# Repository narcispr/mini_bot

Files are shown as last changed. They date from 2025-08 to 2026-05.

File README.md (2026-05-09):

# MiniBot

MiniBot is a easy to mount and moderately cheap robot platform for learning and prototyping in robotics. It is designed to be simple to assemble and use, making it ideal for beginners and hobbyists.

## Construction

To construct the MiniBot, you will need to print the 3D parts available in the [parts](parts) directory. The parts are designed to be printed using a standard FDM 3D printer with PLA.

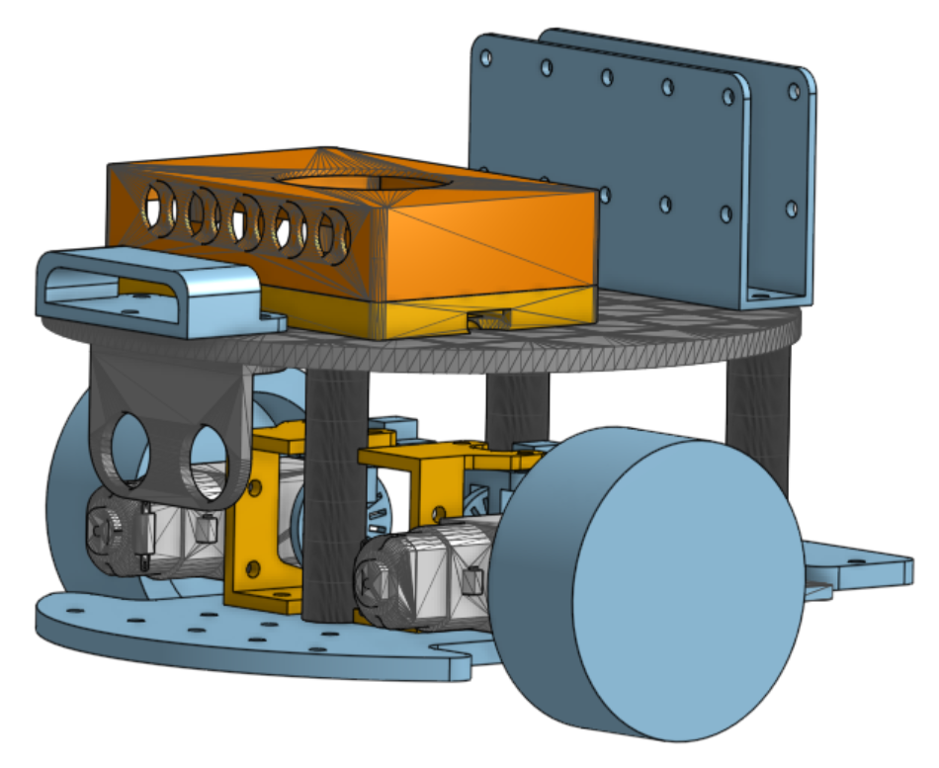
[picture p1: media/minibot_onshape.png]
MiniBot


# Bill of Materials (BOM)

| Item | Qty | Approx. price (EUR) | Notes |
|---|---:|---:|---|
| 3D-printed parts | — | — | See `parts/` directory for STLs and print settings. |
| Arduino Uno (compatible) | 1 | ~€6-20€ | Fully Uno-compatible, USB cable included. |
| Raspberry Pi 4/5 Model B (4GB/8GB) | 1 | ~€60-120€ | Good value & widely available. |
| Adafruit Motor Shield v1 compatible | 1 | ~€4 | v1 compatible shields can be found at Aliexpress and similar. |
| TT motors with wheels (pair) | 1 set | ~€8 | Consider better motors |
| TT wheel encoders (pair) | 1 set | ~€6 | Discs + accessories; pair with IR sensors as needed. |
| Caster wheel | 1 | ~€3 | Any 10–20 mm low-profile caster works. |
| Ultrasonic sensor (HC-SR04) | 1 | ~€2–€6 | Multipacks are cheaper per unit. |
| Webcam (Logitech C270) | 1 | ~€25–€30 | 720p is enough for vision demos. |
| Battery pack for motors | 1 | ~€4–€7 | Option A (4×AA, 6 V) or Option B (6×AA, 9 V). Use quality NiMH cells. |
| Power bank for Raspberry Pi (5 V USB) | 1 | ~€22–€30 | ≥10 000 mAh works; 20 000 mAh gives longer runtime. |
| M3 screws, nuts, spacers | Varies | ~€5–€10 | from 5m to 30m length |

---

**Rough total** 
~€150-210€, excluding 3D prints and AA cells but including Raspberry Pi and many components that you may already have.

### Assembly

There are no detailed assembly instructions yet, but the design is intended to be intuitive. Look at the following images for guidance:

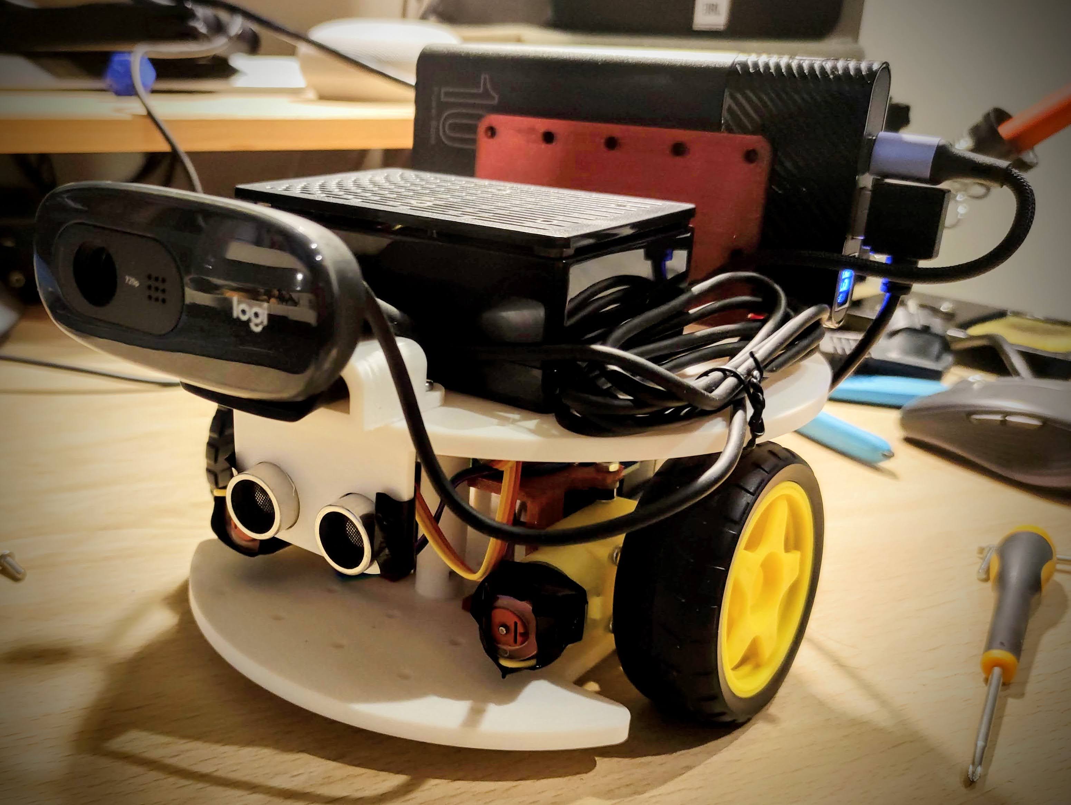
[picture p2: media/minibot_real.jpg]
MiniBot Assembly


## Software
The software for the MiniBot robot is divided in two parts: the Arduino code and the Raspberry Pi code. The communications between the two parts is done using serial communication (USB).

### Arduino Code
The Arduino code is responsible for controlling the motors and reading the sensors. It can be found in the [arduino](arduino) directory. To upload the code to your Arduino board, open the `firmware.ino` file in the Arduino IDE and upload it to your board.

### Raspberry Pi Code
The Raspberry Pi code is responsible for higher-level functions such as image processing and navigation. A ROS2 package is available in this repository. To use it, you will need to have ROS2 installed on your Raspberry Pi. ROS2 Jazzy has been the one used for testing, but other versions may work as well.

There is another repository with the MiniBot description available at [https://github.com/narcispr/mini_bot_description](https://github.com/narcispr/mini_bot_description).

### ROS dependencies

Install the package dependencies from the workspace root:

```bash
cd ~/ros2_ws
rosdep install --from-paths src --ignore-src -r -y
```

For OctoMap support on ROS 2 Jazzy, install:

```bash
sudo apt update
sudo apt install ros-jazzy-octomap-server
```

Optional RViz plugins for visualizing OctoMap messages:

```bash
sudo apt install ros-jazzy-octomap-rviz-plugins
```

If the USB camera node is enabled in `launch/mini_bot.launch.py`, also install:

```bash
sudo apt install ros-jazzy-usb-cam
```

Build and source the workspace after installing dependencies:

```bash
cd ~/ros2_ws
colcon build --packages-select mini_bot
source install/setup.bash
```

### Running with OctoMap Server

`launch/run_robot.launch.py` starts the MiniBot nodes, `robot_state_publisher`, and `octomap_server`. The OctoMap server consumes the MiniBot ultrasonic point cloud:

- input topic: `/range_pointcloud`
- OctoMap subscription: `cloud_in`, remapped to `/range_pointcloud`
- sensor frame: `range_link`
- fixed map frame: `odom`
- resolution: `0.05` m
- maximum sensor range: `3.0` m

Run it with:

```bash
ros2 launch mini_bot run_robot.launch.py
```

The required TF chain is:

```text
odom -> base_link -> range_link
```

`navigation_node` publishes `odom -> base_link`, and `robot_state_publisher` publishes `base_link -> range_link` from the URDF in `mini_bot_description`.

Useful checks:

```bash
ros2 topic info /range_pointcloud
ros2 run tf2_ros tf2_echo odom range_link
ros2 topic echo /projected_map --once
```

The most useful OctoMap outputs are:

- `/projected_map`: 2D occupancy grid projection.
- `/octomap_binary`: compact 3D OctoMap.
- `/octomap_full`: full 3D OctoMap.

### Magnetometer calibration

The robot can use the magnetometer heading as an external orientation source by setting:

```yaml
navigation_node:
  ros__parameters:
    use_external_theta: True
```

There are two simple calibration layers:

1. `mini_bot_node` corrects the raw X/Y magnetometer readings before publishing `/compass_angle`.
2. `navigation_node` maps measured headings to robot-relative headings with `external_theta_calibration_lut`.

#### Automatic raw X/Y calibration

The `mini_bot_node` provides a service that rotates the robot, records magnetometer min/max values, updates the raw X/Y calibration parameters, and writes them back to `config/mini_bot.yaml`.

For calibration, first run with the compass disabled in `config/mini_bot.yaml`:

```yaml
navigation_node:
  ros__parameters:
    use_external_theta: False
```

Start the robot on a flat surface with enough free space to rotate:

```bash
ros2 launch mini_bot run_robot.launch.py
```

Call the service:

```bash
ros2 service call /calibrate_magnetometer std_srvs/srv/Trigger
```

By default, the robot commands `1.0 rad/s` for `10 s` on `/cmd_vel`. The service saves:

```yaml
mag_x_offset_uT
mag_y_offset_uT
mag_x_scale
mag_y_scale
```

The service also reports the observed X/Y/Z ranges. After calibration, restart the robot. Then enable `use_external_theta: True` and tune the heading LUT below so the robot's initial forward direction maps to `0` degrees.

The service parameters are:

```yaml
mini_bot_node:
  ros__parameters:
    mag_calibration_angular_velocity: 1.0
    mag_calibration_duration_sec: 10.0
    mag_calibration_config_file: "/home/narcis/ros2_ws/src/mini_bot/config/mini_bot.yaml"
```

#### Manual raw X/Y calibration

Use this when `/compass_angle` does not cover the full `0..360` range, for example when it moves from `180` to `300` and then goes back to `180`. This usually means the X/Y magnetic readings are offset or stretched.

Start the robot, then rotate it slowly through one full turn while watching `/imu/mag`:

```bash
ros2 topic echo /imu/mag
```

Record the minimum and maximum `magnetic_field.x` and `magnetic_field.y` values. The topic is in Teslas, while the YAML parameters below are in microteslas, so multiply the values by `1e6`.

Calculate:

```text
x_offset = (x_max + x_min) / 2
y_offset = (y_max + y_min) / 2

x_radius = (x_max - x_min) / 2
y_radius = (y_max - y_min) / 2
avg_radius = (x_radius + y_radius) / 2

mag_x_scale = avg_radius / x_radius
mag_y_scale = avg_radius / y_radius
```

Then set these parameters in `config/mini_bot.yaml`:

```yaml
mini_bot_node:
  ros__parameters:
    mag_x_offset_uT: 0.0
    mag_y_offset_uT: 0.0
    mag_x_scale: 1.0
    mag_y_scale: 1.0
    mag_heading_offset_deg: 0.0
```

`mag_heading_offset_deg` is a final constant angle offset. Use it if the heading covers the full circle but `0` degrees does not match the robot's forward direction.

#### Robot heading LUT

After the raw X/Y calibration, measure four stable headings with the robot pointing forward, left, backward and right. Put the measured value first, then the corrected robot-relative heading:

```yaml
navigation_node:
  ros__parameters:
    use_external_theta: True
    external_theta_calibration_lut:
      - 40.0
      - 0.0
      - 150.0
      - 90.0
      - 280.0
      - 180.0
      - 355.0
      - 270.0
```

The LUT is circular, so it can handle the `360 -> 0` wraparound.

#### Sensor orientation

ROS `base_link` convention is:

```text
X forward, Y left, Z up
```

If the magnetometer is mounted with sensor `Y` pointing forward, sensor `X` pointing right, and `Z` pointing up, the mounting is usable, but it is rotated relative to `base_link`. With the current heading formula this is typically equivalent to a `-90` degree correction, so you can use:

```yaml
mag_heading_offset_deg: 270.0
```

If your four-point heading LUT already maps forward to `0`, left to `90`, backward to `180`, and right to `270`, that LUT can absorb this offset too.

Many GY-271 boards are sold with different chips. The Arduino firmware currently uses the `Adafruit_HMC5883_U` library. If an I2C scanner finds the sensor at `0x0D` instead of `0x1E`, the board is probably QMC5883L-compatible and the Arduino firmware should use a QMC5883L library instead.

## To be done

- [ ] MiniBot power is divided in two sources: one for the motors and another for the Raspberry Pi. A better power management system is needed.
- [ ] The HMC5883L magnetometer is not yet working properly. It needs to be fixed or replaced.
- [ ] TT motors are not very accurate. Better motors with encoders would improve the performance of the robot.
- [ ] The caster wheel is not standardized. A better solution is needed.
- [ ] ROS2 package needs to be improved and documented.

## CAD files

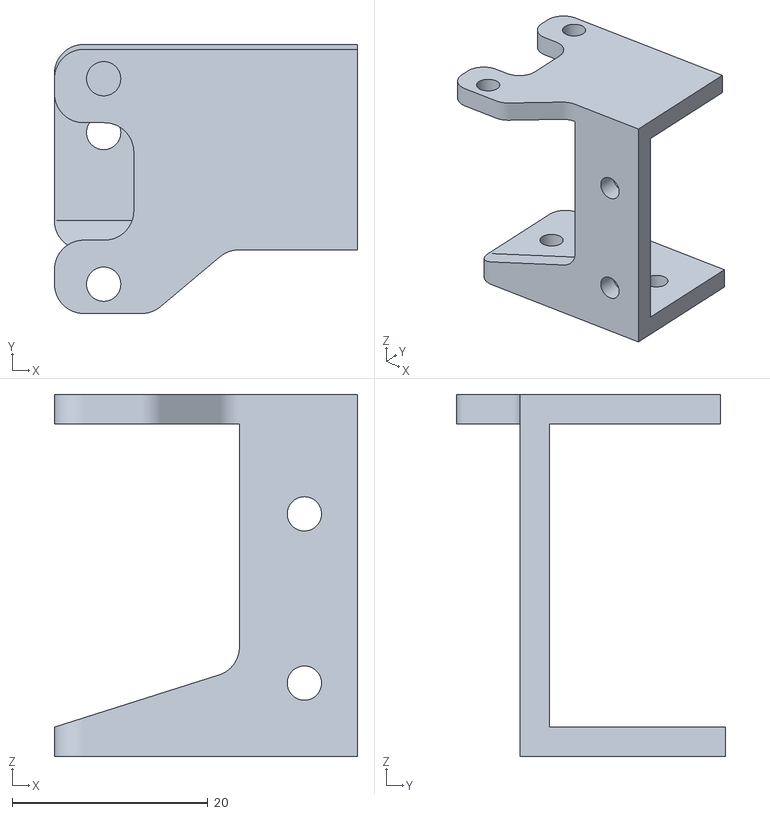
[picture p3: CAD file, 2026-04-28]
parts/motor_holder_right_v3.stl
31.0 x 27.5 x 37.0

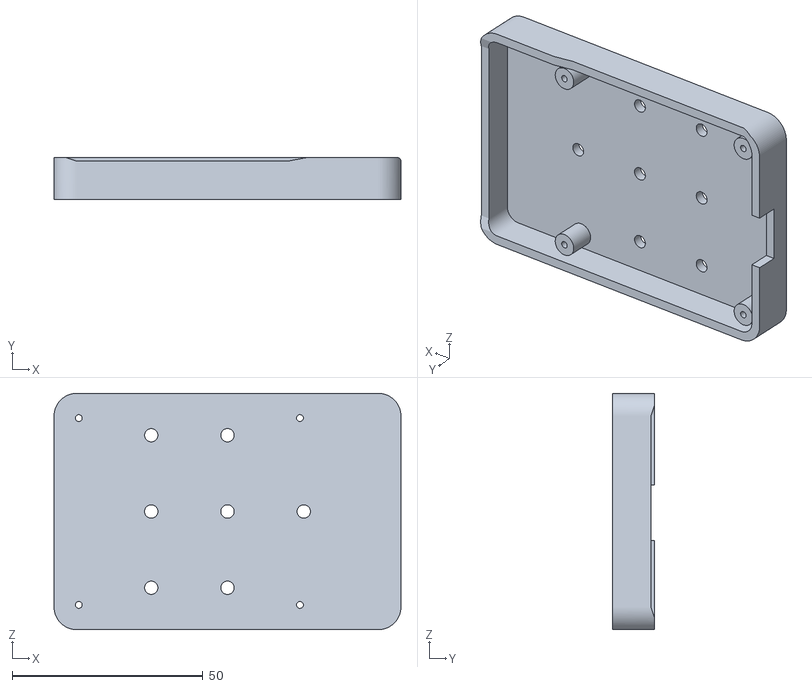
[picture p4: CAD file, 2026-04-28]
parts/raspberry_pi_holder_bottom.stl
91.0 x 11.1 x 62.0

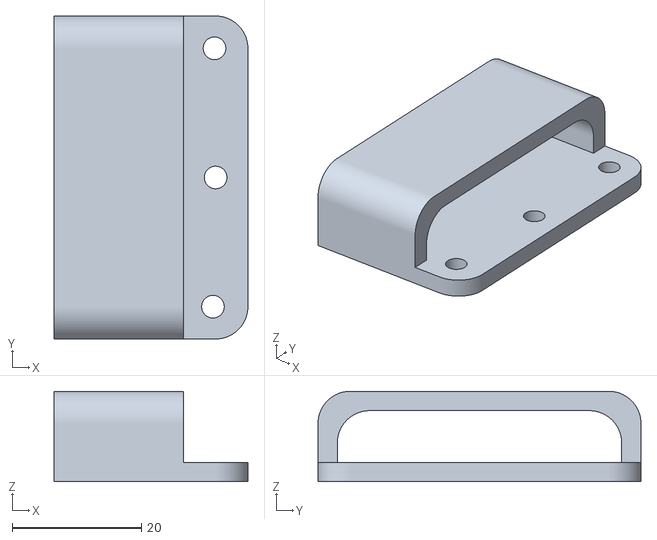
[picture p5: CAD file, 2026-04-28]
parts/webcam_mount.stl
30.0 x 50.0 x 14.0

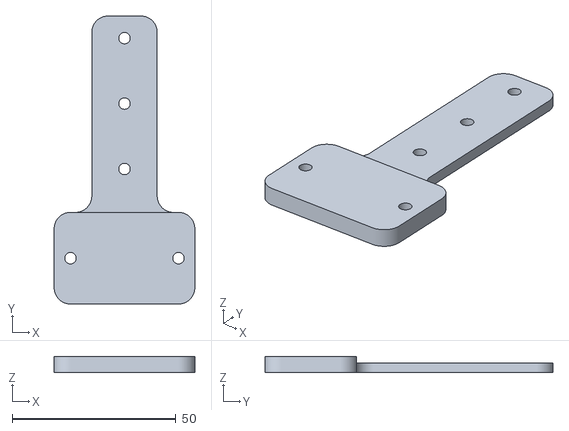
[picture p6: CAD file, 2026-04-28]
parts/dumb_wheel_support_v2.stl
43.0 x 88.0 x 5.00

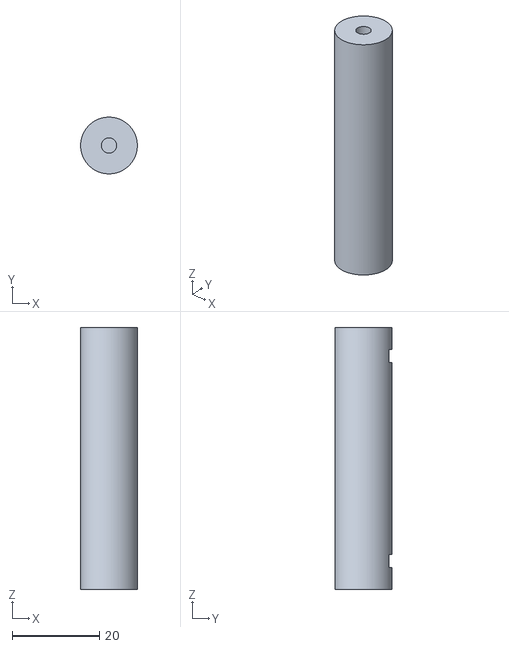
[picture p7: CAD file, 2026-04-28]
parts/rods_60mm.stl
13.0 x 13.0 x 60.0

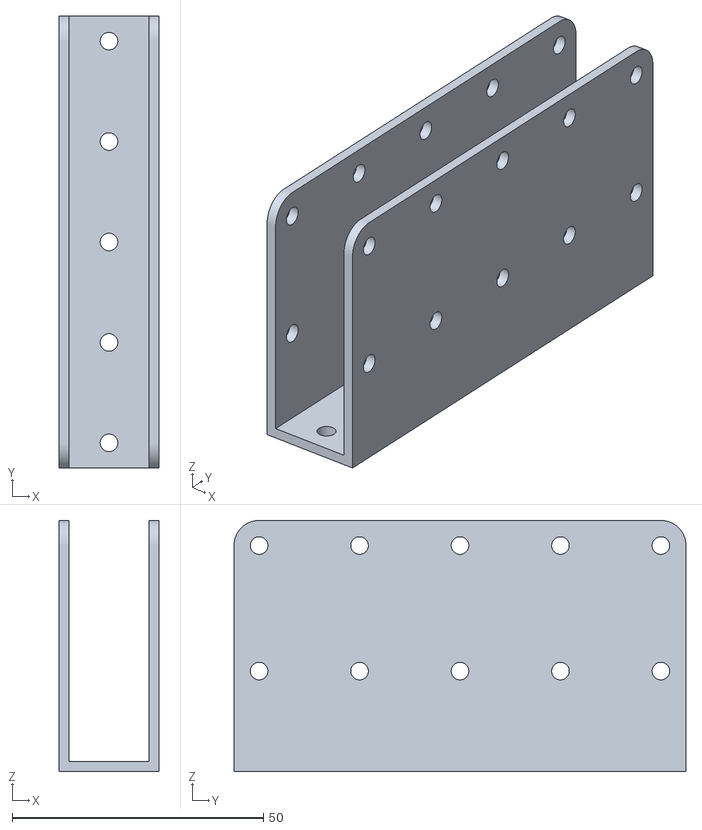
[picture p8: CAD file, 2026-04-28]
parts/battery_holder.stl
20.0 x 90.0 x 50.0

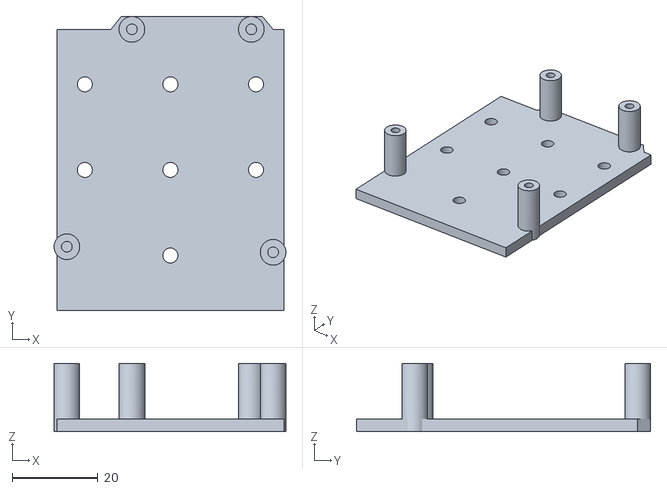
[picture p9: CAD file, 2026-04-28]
parts/Arduino_UNO_holder-Body.stl
54.2 x 68.7 x 16.0

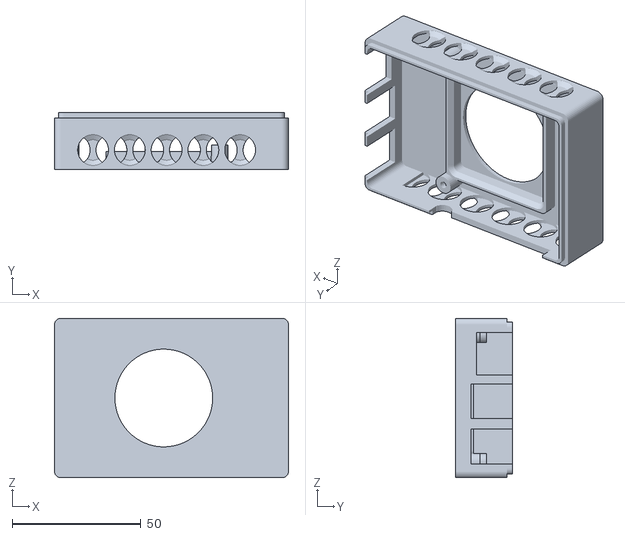
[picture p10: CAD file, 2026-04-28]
parts/Pi_Case_Upper_Tall.stl
91.0 x 22.0 x 62.0

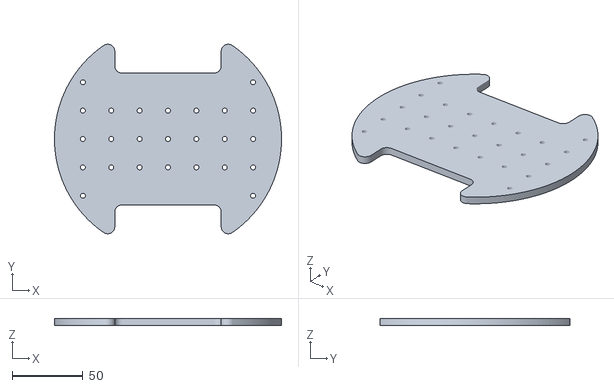
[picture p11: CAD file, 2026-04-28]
parts/wheels_plate.stl
160.0 x 133.6 x 5.00

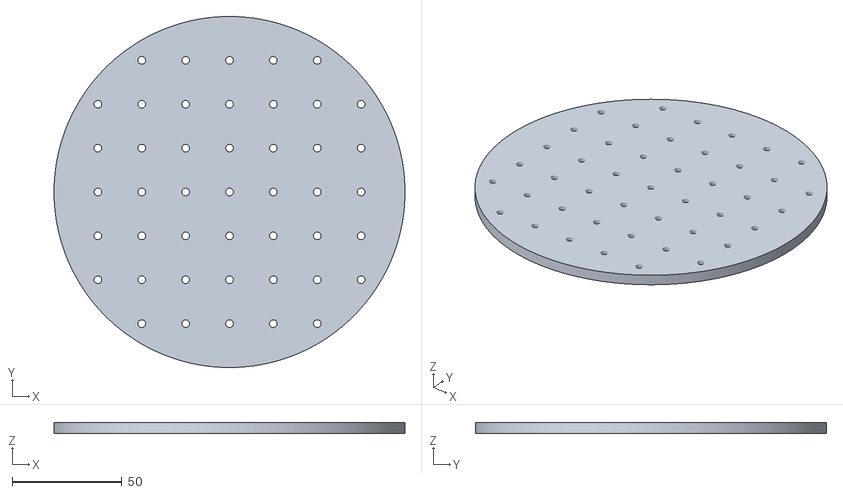
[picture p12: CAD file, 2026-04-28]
parts/plate_160mm.stl
160.0 x 160.0 x 5.00

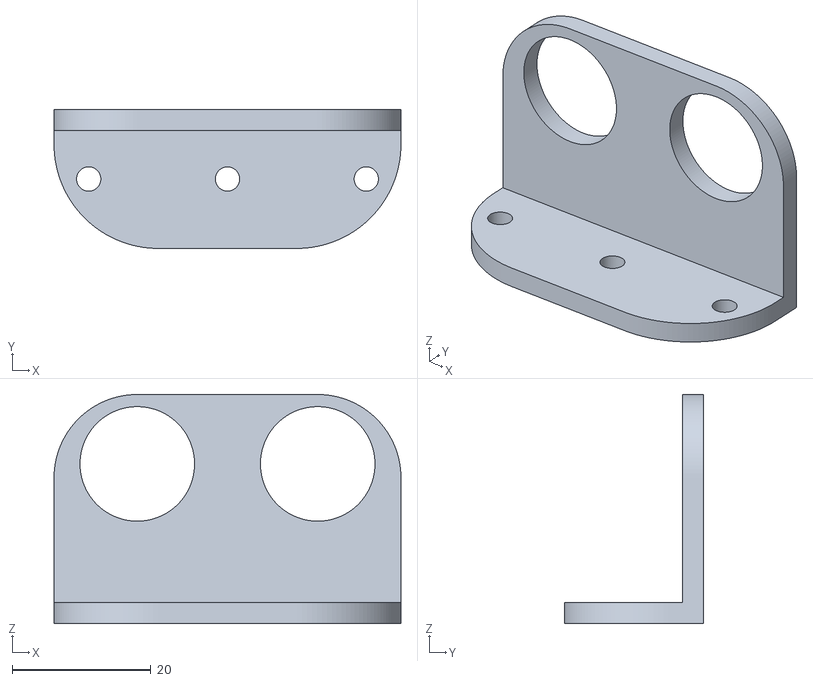
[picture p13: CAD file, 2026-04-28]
parts/JanSpiesZA-54-ORP_Sonar_stand-Body.stl
50.0 x 20.0 x 33.0

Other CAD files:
parts/motor_holder_left_v3.stl

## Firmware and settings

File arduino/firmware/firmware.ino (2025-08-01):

#include "AFMotor.h"
#include <NewPing.h>
#include <Wire.h>
#include <Adafruit_Sensor.h>
#include <Adafruit_HMC5883_U.h>

// Communication Protocol
#define START_BYTE 0xAA
#define END_BYTE   0x55
#define ID_SENSOR_RANGE 0x01
#define ID_SENSOR_ENCODERS 0x02
#define ID_SENSOR_COMPASS 0x03
#define ID_CMD_RPM 0x10

// Crear l'objecte del sensor
Adafruit_HMC5883_Unified compass = Adafruit_HMC5883_Unified(12345);
// CONNECT the compass to the I2C bus
// SCL --> A5
// SDA --> A4

// Ultrasonic sensor
#define MAX_DIST  300
#define TRIG_PIN  A0
#define ECHO_PIN  A1  
uint8_t range[2];
uint16_t dist = 0;
NewPing sonar(TRIG_PIN, ECHO_PIN, MAX_DIST);

// Motors
AF_DCMotor motor_left(3);
AF_DCMotor motor_right(4);

int motor_left_pwm = 0;
int motor_left_state = RELEASE;
int motor_right_pwm = 0;
int motor_right_state = RELEASE;
int motor_watch_dog = 0;

//Encoders
#define ENCODER_LEFT A2
#define ENCODER_RIGHT A3
volatile byte pulses_left;
volatile byte pulses_right;
bool prev_left_state = HIGH;
bool prev_right_state = HIGH;
uint8_t pulses[2];

// Others
#define LOOP_PERIOD_MS  50
unsigned long last_loop_time = 0;

// Divideix un valor de 16 o 32 bits en un array de bytes
void splitToBytes(uint32_t value, uint8_t* buffer, uint8_t num_bytes) {
  for (uint8_t i = 0; i < num_bytes; i++) {
    buffer[i] = (value >> (8 * i)) & 0xFF;
  }
}

void sendMessage(uint8_t id, uint8_t* data, uint8_t len) {
  Serial.write(START_BYTE);
  Serial.write(id);
  Serial.write(len);
  uint8_t checksum = id ^ len;
  for (uint8_t i = 0; i < len; i++) {
    Serial.write(data[i]);
    checksum ^= data[i];
  }
  Serial.write(checksum);
  Serial.write(END_BYTE);
}

void receiveMessage() {
  static enum { WAIT_START, READ_ID, READ_LEN, READ_DATA, READ_CHK, WAIT_END } state = WAIT_START;
  static uint8_t buffer[32];
  static uint8_t idx = 0;
  static uint8_t id, len, checksum;

  while (Serial.available()) {
    uint8_t byte = Serial.read();
    switch (state) {
      case WAIT_START:
        if (byte == START_BYTE) state = READ_ID;
        break;
      case READ_ID:
        id = byte;
        checksum = id;
        state = READ_LEN;
        break;
      case READ_LEN:
        len = byte;
        checksum ^= len;
        idx = 0;
        state = READ_DATA;
        break;
      case READ_DATA:
        buffer[idx++] = byte;
        checksum ^= byte;
        if (idx >= len) state = READ_CHK;
        break;
      case READ_CHK:
        if (byte == checksum) state = WAIT_END;
        else state = WAIT_START;
        break;
      case WAIT_END:
        if (byte == END_BYTE) {
          if (id == ID_CMD_RPM && len == 4) {
            processMotorCMD(buffer);
          }
        }
        state = WAIT_START;
        break;
    }
  }
}

void processMotorCMD(uint8_t* data) {
  motor_left_state  = (data[0] == 0) ? BACKWARD : FORWARD;
  motor_left_pwm    = data[1];
  motor_right_state = (data[2] == 0) ? BACKWARD : FORWARD;
  motor_right_pwm   = data[3];
  motor_watch_dog = 10;
}

void writeMotors() {
  motor_left.run(motor_left_state);
  motor_left.setSpeed(motor_left_pwm);
  motor_right.run(motor_right_state);
  motor_right.setSpeed(motor_right_pwm);
}

void setup() {
  //Init Serial
  Serial.begin(115200);
  
  // Init Motors
  writeMotors();
  
  // Init encoders
  pulses_left = 0;
  pulses_right = 0;
  pinMode(ENCODER_LEFT, INPUT);
  pinMode(ENCODER_RIGHT, INPUT);

  // Init compass
  Wire.begin();

  // Inicialitzar el sensor
  if (!compass.begin()) {
    // This will be handled in the main loop, which will detect
    // the failure (reading all zeros) and send an error code.
  } 
}

void loop() {
  unsigned long now = millis();

  // At every 50 ms:
  if (now - last_loop_time >= (LOOP_PERIOD_MS)) {
    // read range sensor
    last_loop_time = now;
    unsigned int dist = sonar.ping_cm();
    splitToBytes(dist, range, 2);
    sendMessage(ID_SENSOR_RANGE, range, 2);
    
    // Send Encoder Pulses
    pulses[0] = pulses_left;
    pulses[1] = pulses_right;
    pulses_left = 0;
    pulses_right = 0;
    sendMessage(ID_SENSOR_ENCODERS, pulses, 2);
    
    // Process motor commands
    receiveMessage();
    writeMotors();
    if (motor_watch_dog <= 0) {
      motor_left_pwm = 0;
      motor_left_state = BRAKE;
      motor_right_pwm = 0;
      motor_right_state = BRAKE;
    }
    else {
      motor_watch_dog = motor_watch_dog - 1;
    }

    // Read compass
    sensors_event_t event;
    compass.getEvent(&event);
    uint8_t mag_data[6];
    if (event.magnetic.x == 0 && event.magnetic.y == 0 && event.magnetic.z == 0) {
      // Send error code (all 0xFF)
      for(int i=0; i<6; i++) mag_data[i] = 0xFF;
    } else {
      // Scale and convert to signed 16-bit integers (multiplied by 100)
      int16_t mag_x = (int16_t)(event.magnetic.x * 100.0);
      int16_t mag_y = (int16_t)(event.magnetic.y * 100.0);
      int16_t mag_z = (int16_t)(event.magnetic.z * 100.0);

      // Pack into byte array (Little Endian)
      mag_data[0] = mag_x & 0xFF;
      mag_data[1] = (mag_x >> 8) & 0xFF;
      mag_data[2] = mag_y & 0xFF;
      mag_data[3] = (mag_y >> 8) & 0xFF;
      mag_data[4] = mag_z & 0xFF;
      mag_data[5] = (mag_z >> 8) & 0xFF;
    }
    sendMessage(ID_SENSOR_COMPASS, mag_data, 6);
  } 

  // At Every iteration: Read encoder pulses bu polling
  bool current_left_state = digitalRead(ENCODER_LEFT);
  bool current_right_state = digitalRead(ENCODER_RIGHT);

  if (prev_left_state == HIGH && current_left_state == LOW) {
    pulses_left++;
  }
  if (prev_right_state == HIGH && current_right_state == LOW) {
    pulses_right++;
  }
  prev_left_state = current_left_state;
  prev_right_state = current_right_state;
}

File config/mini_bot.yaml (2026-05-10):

# Parameters for the mini_bot_node
mini_bot_node:
  ros__parameters:
    wheel_radius: 0.0325
    wheel_base: 0.15
    dt: 0.05
    serial_port: "/dev/ttyACM0"
    pulses_window: 5
    pulses_per_revolution: 20
    # Simple 2D magnetometer calibration used before calculating compass_angle.
    # Rotate the robot once and record min/max x/y from /imu/mag in microteslas.
    # offset=(max+min)/2, scale=avg_radius/axis_radius.
    mag_x_offset_uT: -3.68
    mag_y_offset_uT: -29.045
    mag_x_scale: 1.00558
    mag_y_scale: 0.994477
    mag_heading_offset_deg: 0.0
    mag_calibration_angular_velocity: 1.25
    mag_calibration_duration_sec: 15.0
    mag_calibration_config_file: "/home/narcis/ros2_ws/src/mini_bot/config/mini_bot.yaml"

# Parameters for the navigation_node
navigation_node:
  ros__parameters:
    wheel_radius: 0.0325
    wheel_base: 0.15
    dt: 0.05
    use_external_theta: True
    # Magnetometer heading calibration used when use_external_theta is true.
    # Format: measured_degrees, corrected_degrees. Measure the robot pointing
    # forward, left, backward and right, then replace the measured values below.
    external_theta_calibration_lut:
      - 3.0
      - 0.0
      - 93.0
      - 90.0
      - 183.0
      - 180.0
      - 273.0
      - 270.0

# Parameters for the controller_node
controller_node:
  ros__parameters:
    max_v: 0.5  #m/s
    max_w: 3.14 #rad/s
    dt: 0.1
    max_pwm: 255.0
    cmd_vel_timeout: 0.5
    gain_pid: 0.25
    # PID parameters used by controller_node.py.
    pid_v:
      kp: 1.0
      ki: 0.0
      kd: 0.2
      integral_max: 0.1
    pid_w:
      kp: 1.5
      ki: 0.0
      kd: 0.0
      integral_max: 0.1
    angle_pid:
      kp: 0.8
      ki: 0.0
      kd: 0.0
      integral_max: 0.0
    max_v_goal: 0.3
    max_w_goal: 1.15
    goal_tolerance: 0.1
    goal_angle_tolerance: 0.3
    # LUTs used by controller_node.py. They are flat lists reshaped in the node.
    velocity_to_pwm_lut_v:
      - 0.0
      - 0.0
      - 0.15
      - 125.0
      - 0.25
      - 150.0
      - 0.4
      - 200.0
      - 0.5
      - 225.0
      - 0.6
      - 255.0
    velocity_to_pwm_lut_w:
      - 0.0
      - 0.0
      - 0.8
      - 125.0
      - 0.85
      - 135.0
      - 2.3
      - 155.0
      - 4.0
      - 185.0

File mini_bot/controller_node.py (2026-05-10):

import rclpy
from rclpy.duration import Duration
from rclpy.node import Node
from geometry_msgs.msg import PoseStamped, Twist
from nav_msgs.msg import Odometry
from std_msgs.msg import Int16MultiArray
import numpy as np
from mini_bot.utils.pid import PID
import tf2_geometry_msgs  # noqa: F401 - registers geometry_msgs transforms with tf2
import tf2_ros

import math

from mini_bot.utils.utils import quaternion_to_euler


class ControllerNode(Node):
    def __init__(self):
        super().__init__('controller_node')

        # Declare parameters
        self.declare_parameter('max_v', 0.5)
        self.declare_parameter('max_w', 3.14)
        self.declare_parameter('max_pwm', 255.0)
        self.declare_parameter('cmd_vel_timeout', 0.2)
        self.declare_parameter('dt', 0.05)
        self.declare_parameter('gain_pid', 0.5)
        self.declare_parameter('pid_v.kp', 1.0)
        self.declare_parameter('pid_v.ki', 0.0)
        self.declare_parameter('pid_v.kd', 0.2)
        self.declare_parameter('pid_v.integral_max', 0.1)
        self.declare_parameter('pid_w.kp', 1.0)
        self.declare_parameter('pid_w.ki', 0.0)
        self.declare_parameter('pid_w.kd', 0.2)
        self.declare_parameter('pid_w.integral_max', 0.1)
        self.declare_parameter('angle_pid.kp', 1.0)
        self.declare_parameter('angle_pid.ki', 0.1)
        self.declare_parameter('angle_pid.kd', 0.05)
        self.declare_parameter('angle_pid.integral_max', 0.2)
        self.declare_parameter('max_v_goal', 0.2)
        self.declare_parameter('max_w_goal', 1.0)
        self.declare_parameter('goal_tolerance', 0.1)
        self.declare_parameter('goal_angle_tolerance', 0.3)

        self.declare_parameter(
            'velocity_to_pwm_lut_v',
            [0.0, 0.0, 0.01, 125.0, 0.25, 150.0, 0.4, 200.0, 0.5, 225.0, 0.6, 255.0],
        )
        self.declare_parameter(
            'velocity_to_pwm_lut_w',
            [0.0, 0.0, 0.01, 125.0, 0.85, 135.0, 2.3, 155.0, 4.0, 185.0],
        )

        # Get parameters
        self.max_v = abs(self.get_parameter('max_v').get_parameter_value().double_value)
        self.max_w = abs(self.get_parameter('max_w').get_parameter_value().double_value)
        self.max_pwm = self.get_parameter('max_pwm').get_parameter_value().double_value
        self.cmd_vel_timeout = self.get_parameter('cmd_vel_timeout').get_parameter_value().double_value
        self.dt = self.get_parameter('dt').get_parameter_value().double_value
        self.gain_pid = self.get_parameter('gain_pid').get_parameter_value().double_value

        pid_v_kp = self.get_parameter('pid_v.kp').get_parameter_value().double_value
        pid_v_ki = self.get_parameter('pid_v.ki').get_parameter_value().double_value
        pid_v_kd = self.get_parameter('pid_v.kd').get_parameter_value().double_value
        pid_v_integral_max = self.get_parameter('pid_v.integral_max').get_parameter_value().double_value
        pid_w_kp = self.get_parameter('pid_w.kp').get_parameter_value().double_value
        pid_w_ki = self.get_parameter('pid_w.ki').get_parameter_value().double_value
        pid_w_kd = self.get_parameter('pid_w.kd').get_parameter_value().double_value
        pid_w_integral_max = self.get_parameter('pid_w.integral_max').get_parameter_value().double_value
        angle_pid_kp = self.get_parameter('angle_pid.kp').get_parameter_value().double_value
        angle_pid_ki = self.get_parameter('angle_pid.ki').get_parameter_value().double_value
        angle_pid_kd = self.get_parameter('angle_pid.kd').get_parameter_value().double_value
        angle_pid_integral_max = self.get_parameter(
            'angle_pid.integral_max'
        ).get_parameter_value().double_value
        self.max_v_goal = abs(self.get_parameter('max_v_goal').get_parameter_value().double_value)
        self.max_w_goal = abs(self.get_parameter('max_w_goal').get_parameter_value().double_value)
        self.goal_tolerance = abs(self.get_parameter('goal_tolerance').get_parameter_value().double_value)
        self.goal_angle_tolerance = abs(
            self.get_parameter('goal_angle_tolerance').get_parameter_value().double_value
        )

        self.velocity_to_pwm_lut_v = self.load_lut('velocity_to_pwm_lut_v')
        self.velocity_to_pwm_lut_w = self.load_lut('velocity_to_pwm_lut_w')

        # TF Buffer and Listener
        self.tf_buffer = tf2_ros.Buffer()
        self.tf_listener = tf2_ros.TransformListener(self.tf_buffer, self)

        # Store current odometry
        self.current_v = 0.0
        self.current_w = 0.0
        self.current_pose = None
        self.last_odom_time = None

        # Store desired velocities
        self.desired_v = 0.0
        self.desired_w = 0.0
        self.desired_last_time = self.get_clock().now()

        # Go-to-goal state
        self.goal_pose = None
        self.execute_goto = False

        # PID controllers
        self.pid_v = PID(kp=pid_v_kp, ki=pid_v_ki, kd=pid_v_kd, integral_max=pid_v_integral_max)
        self.pid_w = PID(kp=pid_w_kp, ki=pid_w_ki, kd=pid_w_kd, integral_max=pid_w_integral_max)
        self.angle_pid = PID(
            kp=angle_pid_kp,
            ki=angle_pid_ki,
            kd=angle_pid_kd,
            integral_max=angle_pid_integral_max,
        )
        self.last_pid_time = self.get_clock().now()
        self.last_goal_time = self.get_clock().now()

        # Publishers and subscribers
        self.pwm_pub = self.create_publisher(Int16MultiArray, 'pwm_setpoints', 10)
        self.create_subscription(Twist, 'cmd_vel', self.cmd_vel_callback, 10)
        self.create_subscription(Odometry, 'odom', self.odom_callback, 10)
        self.create_subscription(PoseStamped, '/goal_pose', self.goal_pose_callback, 10)

        # Timers
        self.create_timer(self.dt, self.goto_goal_controller)
        self.create_timer(self.dt, self.apply_velocity)

    def load_lut(self, parameter_name):
        lut_param = self.get_parameter(parameter_name).value
        lut = np.array(lut_param, dtype=float)
        if lut.size == 0 or lut.size % 2 != 0:
            raise ValueError(f'{parameter_name} must contain velocity/PWM pairs')

        lut = lut.reshape(-1, 2)
        if np.any(np.diff(lut[:, 0]) < 0.0):
            raise ValueError(f'{parameter_name} velocity values must be sorted')

        return lut

    def cmd_vel_callback(self, msg: Twist):
        if self.execute_goto:
            self.get_logger().info('Cancelling go-to-goal because cmd_vel was received.')
        self.execute_goto = False
        self.goal_pose = None
        self.desired_v = float(np.clip(msg.linear.x, -self.max_v, self.max_v))
        self.desired_w = float(np.clip(msg.angular.z, -self.max_w, self.max_w))
        self.desired_last_time = self.get_clock().now()

    def odom_callback(self, msg: Odometry):
        self.current_v = msg.twist.twist.linear.x
        self.current_w = msg.twist.twist.angular.z
        self.current_pose = msg.pose.pose
        self.last_odom_time = self.get_clock().now()
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

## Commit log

2025-05-17 Add a more precise control of the motors. To be finalized
2025-07-14 Add encoders read, not tested
2025-07-14 Try to read encoders from ROS2 not working...
    [bot_comms.py, firmware.ino, mini_bot_node.py]
2025-07-15 Change encoder pulses reading from interrupt (onli D2 and D3) to polling
2025-07-15 Publish wheels speed
2025-07-21 feat: Add controller node with PID control and LUTs; refactor parameters to YAML; use Gemini CLI for development.
2025-07-21 Improve calibtation function ensuring 2s for velocity stabilization
2025-07-26 Add thread to read sensors, increase seria port speed, and add sign in encoders data (TBC)
2025-07-28 feat: Use Int16MultiArray for PWM values
2025-07-28 Refactor: Improve wheel direction logic in mini_bot_node.py
2025-07-28 Fix: Add tf_transformations import and ROS 2 resource file
    [navigation_node.py]
2025-07-28 Refactor: Improve communication and motor control logic
    - Corrected serial baud rate mismatch between Arduino firmware and ROS node.
    - Enhanced compass error handling in the ROS node.
    - Changed motor watchdog default state to BRAKE in Arduino firmware for safer stops.
    - Simplified PWM message building by removing redundant direction returns.
    - Removed unused direction variables in the ROS node.
    - Implemented PWM value clamping in the ROS node to match hardware limits.
    [bot_comms.py, firmware.ino, mini_bot_node.py]
2025-08-01 feat: Implement HMC5883 raw data processing and refactor compass handling\n\n- Arduino firmware now sends raw 3-axis magnetometer data (X, Y, Z) as 16-bit integers.\n- ROS2 node processes this raw da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
2025-08-01 Issues with tf-transformations, compass reading and controller launch
    [bot_comms.py, mini_bot.yaml, navigation_node.py]
2025-08-01 feat(navigation): Replace tf_transformations with numpy
    Removes the dependency on by implementing a NumPy-based function. This resolves installation issues on the target system.
    [navigation_node.py]
2025-08-01 fix(node): Correctly unpack compass data
    The struct.unpack function expects a bytes-like object, but it was receiving a list of integers. This commit fixes the TypeError by converting the payload to a bytearray before unpacking.
    [mini_bot_node.py]
2025-08-01 refactor(launch): Use standard ROS2 parameter loading
    Refactors the launch and configuration files to align with ROS2 best practices.
    - launch/mini_bot.launch.py: No longer manually parses the YAML file. It now passes the configuration file path directly to the nodes, simplifying the launch script and resolving a TypeError caused by incorrect parameter types.
    - config/mini_bot.yaml: Restructured to use node-specific ros__parameters sections. Implements YAML anchors (&) and aliases (*) to define common parameters once and reuse them, avoiding duplication.
    - mini_bot/controller_node.py: Adjusted to correctly reshape the flattened velocity_to_pwm_lut array that results from the new YAML load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
    [controller_node.py, mini_bot.yaml]
2025-08-01 feat(controller): Improve calibration output format
    Updates the calibrate_callback service to print the newly generated look-up tables in a YAML-friendly format. This makes it easy for users to copy and paste the calibration results directly into the 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
2025-08-01 fix(ros): resolve parameter parsing and import errors
    - Corrected the YAML structure in `config/mini_bot.yaml` to remove the use of anchors, which was causing parsing failures with `rclpy`.
    - Fixed an `ImportError` in `mini_bot/controller_node.py` by removing `TriggerResponse` from the `std_srvs.srv` import, as it is not available in the current ROS2 distribution.
    [controller_node.py, mini_bot.yaml]
2025-08-01 Disable smooth PWM accel and disable PID. There are issues with /calibrate function
    [controller_node.py]
2025-08-02 Add a timer for the controller node
2025-08-02 Calibrate LUT rad/s to PWM
2025-08-02 Fix bug with time vars initialization
    [controller_node.py]
2025-08-02 Tunned calibration and PID params and add zero-trick in controller
2025-08-02 Enable TFs, issue in RViz... TBF
    [mini_bot.yaml]
2025-08-03 Fix wheel base length and add launch that includes URDF from mini_bot_description
    [mini_bot.yaml]
2025-08-03 Publish joint_state position in addition of velocity
2025-08-03 Deleted TF broadcasting (not necessary and causing issues) and fixed issue with w computation in differential drive kinematics
    [navigation_node.py]
2025-08-03 Add again TF broadcast from odom to base_link frames
2025-08-03 Change lenght between wheels from 0.15 to 0.16
2025-08-03 Remove PID in goto functionality
2025-08-03 Add PID only for W in goto
2025-09-15 Add Readme and STL parts
    [Arduino_UNO_holder-Body.stl, JanSpiesZA-54-ORP_Sonar_stand-Body.stl, Pi_Case_Upper_Tall.stl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]
2026-04-28 Fixed spin issues using codex
    [bot_comms.py, mini_bot_node.py]
2026-05-09 Add PID to controller lite
2026-05-09 Add compass calibration procedure
2026-05-09 Reduce max distance for range sensor in octomap server
2026-05-09 Fixed issu in calibration
    [mini_bot.yaml, mini_bot_node.py]
2026-05-09 Add calibrated magnetometer data
